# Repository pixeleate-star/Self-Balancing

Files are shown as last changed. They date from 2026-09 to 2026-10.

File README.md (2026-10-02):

# Self-Balancing Robot

This is the whole codebase for my **self-balancing robot**. It has the code, circuit connections and setup information needed to make your own two-wheel self-balancing robot using an **ESP32, MPU9250, TB6612FNG motor driver and two BO motors**.

The main idea behind this project is to build a small two-wheel robot that can balance itself upright using an **MPU9250 IMU**. The MPU9250 measures the robot's tilt and angular velocity, while a **PID controller** continuously adjusts the motors to keep the robot balanced.

The ESP32 handles the sensor readings and PID calculations, while the TB6612FNG controls the two BO motors.

## Features

- Self-balancing two-wheel robot
- ESP32 as the main controller
- MPU9250 accelerometer and gyroscope
- PID-based balance control
- Complementary filter for tilt estimation
- Gyroscope calibration on startup
- Adjustable PID parameters
- Adjustable target balance angle
- Motor dead-zone compensation
- Left and right motor trim
- Automatic fall detection
- Automatic motor shutdown when the robot falls
- High-frequency PWM motor control
- TB6612FNG dual motor driver
- Battery powered
- Compact and easy-to-build design

## BOM – Bill of Materials

| Component | Quantity | Price (USD) | Purpose | Purchase Link |
|---|:---:|---:|---|:---:|
| ESP32 Development Board | 1 | $4.18 | Main controller and PID processing | [Buy Here](https://robocraze.com/products/esp32-development-board-with-cp2102-wifi-bluetooth-dual-core-30-pin) |
| MPU9250 Module | 1 | $3.87 | Accelerometer and gyroscope for tilt sensing | [Buy Here](https://robocraze.com/products/mpu-9250-module) |
| 200 RPM BO Motor | 2 | $0.63 each | Left and right drive motors | [Buy Here](https://robocraze.com/products/200-rpm-single-shaft-bo-motor-straight) |
| BO Motor Wheels | 1 pack (4 pcs) | $0.94 | Robot wheels | [Buy Here](https://robocraze.com/products/bo-motor-wheels-4-pcs) |
| TB6612FNG Dual DC Motor Driver | 1 | $1.41 | Drives both BO motors | [Buy Here](https://robocraze.com/products/tb6612fng-dual-dc-motor-driver) |
| Battery | 2 | $2 | Power source | [Buy Here](https://robocraze.com/products/3-7v-2500mah-18650-li-ion-battery) |
| Battery Holder | 1 | $0.25 | Battery connection | [Buy Here](https://robocraze.com/products/18650-2-cell-holder) |
| Buck Convertor | 1 | $0.6 | To give stable 5V to ESP | [Buy Here](https://robocraze.com/products/lm2596-dc-dc-buck-module) |
| Jumper Wires | As required | — | Electrical connections | - |
| 3D Printed Parts | As required | — | Robot frame and structural parts | Self Printed |

## Circuit Diagram

I have added the complete circuit diagram below. You can use it as a reference while wiring your own self-balancing robot.


I know it looks a mesh so here's a link to circuit you can check it out https://app.cirkitdesigner.com/project/33cf55be-d292-4ee9-8185-b1da4f74aae1

### Main Connections

**MPU9250 → ESP32**

| MPU9250 | ESP32 |
|---|---|
| VCC | 3.3V |
| GND | GND |
| SDA | GPIO 21 |
| SCL | GPIO 22 |

**TB6612FNG → ESP32**

| TB6612FNG | ESP32 |
|---|---|
| AIN1 | GPIO 25 |
| AIN2 | GPIO 26 |
| PWMA | GPIO 27 |
| BIN1 | GPIO 32 |
| BIN2 | GPIO 33 |
| PWMB | GPIO 14 |
| STBY | GPIO 13 |
| VCC | 3.3V |
| GND | GND |

**Motors**

| TB6612FNG | Motor |
|---|---|
| AO1 / AO2 | Left BO Motor |
| BO1 / BO2 | Right BO Motor |

The motor power supply should be connected to the **VM** input of the TB6612FNG according to the voltage requirements of your motors.

The ESP32 and MPU9250 should use a suitable regulated supply, and **all grounds must be connected together**.

## How to Build this...

**step 1:** First get all the components mentioned in the BOM. The main parts required are the ESP32, MPU9250, TB6612FNG, two BO motors, wheels and a suitable battery.

**step 2:** Connect the MPU9250 to the ESP32. Connect SDA to GPIO 21 and SCL to GPIO 22. Connect VCC to 3.3V and GND to GND.

**step 3:** Connect the TB6612FNG to the ESP32 according to the connection table above. Connect the two BO motors to the A and B motor outputs.

**step 4:** Connect the motor battery to the VM and GND terminals of the TB6612FNG. Make sure the battery voltage is suitable for the motors and motor driver.

**step 5:** Connect the ESP32 power supply separately through a suitable regulated supply if required. Do not connect an unregulated motor battery directly to a 3.3V ESP32 pin.

**step 6:** Upload the self-balancing code to the ESP32. In Arduino IDE select the appropriate ESP32 board for your hardware.

**step 7:** Once the ESP32 starts, keep the robot completely still and upright during startup. The code takes multiple readings from the MPU9250 gyroscope and calculates the gyro bias automatically.

**step 8:** After calibration, hold the robot and slowly tilt it forward and backward. Check the motor direction before allowing the robot to stand freely.

When the robot tilts forward:

**Forward tilt → Motors should drive forward → Robot returns upright**

When the robot tilts backward:

**Backward tilt → Motors should drive backward → Robot returns upright**

If the motor direction is reversed, invert the PID output in the code.

**step 9:** Place the robot on a flat surface and carefully allow it to balance. Start with conservative PID values and tune the controller gradually.

**step 10:** Finally, assemble everything inside the robot frame. The exact placement of the MPU9250 matters because its orientation determines how the robot measures its tilt.

## PID Tuning

The main PID parameters can be adjusted directly in the code:

float Kp = 28.0;
float Ki = 0.6;
float Kd = 1.2;

float targetAngle = 0.0;

The parameters control the balancing behavior:

| Parameter | Purpose |
|---|---|
| `Kp` | Controls how strongly the robot reacts to tilt |
| `Ki` | Corrects long-term balance error |
| `Kd` | Controls damping and reduces oscillation |
| `targetAngle` | Sets the desired upright angle |

For tuning, start with:

Ki = 0;

Increase `Kp` until the robot starts reacting strongly to falling.

Then increase `Kd` until the robot becomes less oscillatory.

Finally, add a small amount of `Ki` if the robot consistently leans in one direction.

## Motor Calibration

The motors may not rotate at exactly the same speed even when they receive the same PWM value.

The code includes adjustable motor trim:

float leftTrim = 1.00;
float rightTrim = 1.00;

If the robot constantly moves toward one side while balancing, these values can be adjusted.

For example:

float leftTrim = 1.00;
float rightTrim = 0.96;

The exact values depend on the motors, gearbox, wheels and physical construction of the robot.

## Motor Dead Zone

BO motors usually do not start moving at very low PWM values.

The code therefore includes:

int motorDeadZone = 55;

If the motors don't respond to small corrections, increase this value.

If the robot makes unnecessarily large movements around the balance point, reduce it.

## Fall Detection

The robot automatically stops the motors when the measured angle exceeds the configured safety limit:

float fallAngle = 35.0;

This prevents the motors from continuously running when the robot has already fallen over.

After the robot is placed upright again, the controller can resume balancing.

## Code

The main code uses:

- `Wire.h` for I²C communication with the MPU9250
- MPU9250 accelerometer for tilt estimation
- MPU9250 gyroscope for angular velocity
- Complementary filter for stable angle estimation
- PID control for balancing
- ESP32 PWM for motor control
- TB6612FNG for driving the two BO motors

The main parameters can be adjusted directly in the code:

float Kp = 28.0;
float Ki = 0.6;
float Kd = 1.2;

float targetAngle = 0.0;

float complementaryAlpha = 0.98;

int motorDeadZone = 55;

float leftTrim = 1.00;
float rightTrim = 1.00;

## Known Issues

1. The robot requires accurate PID tuning for stable balancing.
2. The motor direction depends on the physical wiring of the BO motors.
3. The MPU9250 needs to remain still during startup gyro calibration.
4. Different MPU9250 modules can have slightly different gyro offsets.
5. Motor speed can vary between individual BO motors.
6. The physical position and orientation of the MPU9250 affects the balance angle.
7. Battery voltage affects motor response and balancing performance.
8. Wheel size and robot center of gravity significantly affect stability.
9. Very low PWM values may not be enough to start the BO motors.
10. A poorly centered or mechanically flexible frame can make balancing significantly harder.
11. The robot can become unstable if the battery voltage drops too low.
12. The PID parameters may need to be changed when the robot's weight, wheels or motor gearing are changed.

## CAD Models





## Working Principle

The MPU9250 continuously measures the robot's orientation.

The accelerometer provides information about the direction of gravity, while the gyroscope measures how quickly the robot is rotating.

These measurements are combined using a **complementary filter** to estimate the robot's current tilt angle.

The PID controller then calculates how much the motors need to move:

MPU9250
   ↓
Accelerometer + Gyroscope
   ↓
Complementary Filter
   ↓
Tilt Angle
   ↓
PID Controller
   ↓
Motor Output
   ↓
TB6612FNG
   ↓
BO Motors
   ↓
Robot moves back toward upright position

The controller continuously repeats this process at a high frequency, allowing the robot to make rapid corrections and remain balanced.

## Final Result

The whole idea is pretty simple but the control system makes it interesting — instead of manually controlling the robot, the robot continuously measures its own tilt and moves the wheels automatically to keep itself upright.

full video---- https://drive.google.com/file/d/15Oyu7o3CPmcscNef3DqKq84Rv_wBlsnM/view?usp=sharing

It is a compact introduction to **IMU sensing, sensor fusion, PID control, motor control and embedded robotics**, all combined into one project.

working video: https://youtube.com/shorts/BoeQEbhFIXY

mine bot------


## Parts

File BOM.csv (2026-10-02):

Component | Quantity | Price (USD) | Purpose | Purchase Link
ESP32 Development Board | 1 | $4.18 | Main controller and PID processing | https://robocraze.com/products/esp32-development-board-with-cp2102-wifi-bluetooth-dual-core-30-pin
MPU9250 Module | 1 | $3.87 | Accelerometer and gyroscope for tilt sensing | https://robocraze.com/products/mpu-9250-module
200 RPM BO Motor | 2 | $0.63 each | Left and right drive motors | https://robocraze.com/products/200-rpm-single-shaft-bo-motor-straight
BO Motor Wheels | 1 pack (4 pcs) | $0.94 | Robot wheels | https://robocraze.com/products/bo-motor-wheels-4-pcs
TB6612FNG Dual DC Motor Driver | 1 | $1.41 | Drives both BO motors | https://robocraze.com/products/tb6612fng-dual-dc-motor-driver
Battery | 2 | $2 | Power source | https://robocraze.com/products/3-7v-2500mah-18650-li-ion-battery
Battery Holder | 1 | $0.25 | Battery connection | https://robocraze.com/products/18650-2-cell-holder
Buck Convertor | 1 | $0.6 | To give stable 5V to ESP | https://robocraze.com/products/lm2596-dc-dc-buck-module
Jumper Wires | As required | — | Electrical connections | -
3D Printed Parts | As required | — | Robot frame and structural parts | Self Printed

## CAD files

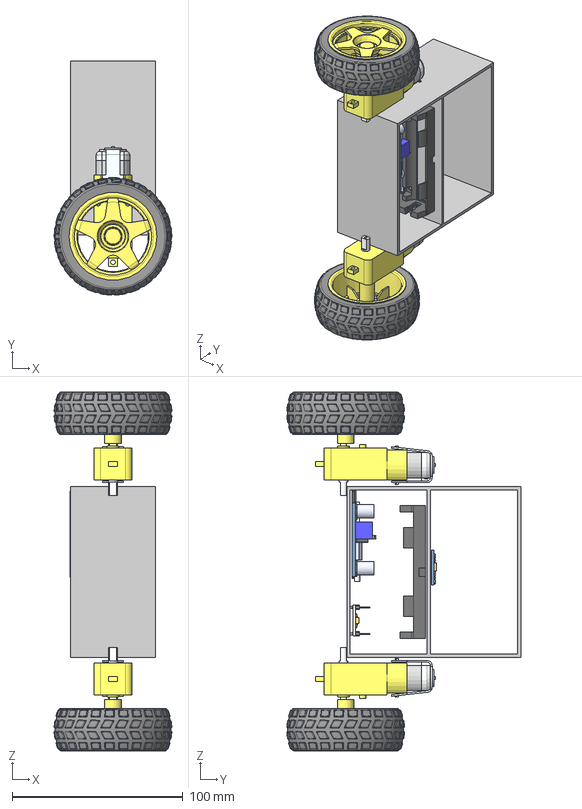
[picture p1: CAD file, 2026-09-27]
CAD/self balancing.step
68.9 x 137.1 x 210.0 mm

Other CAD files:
CAD/self balancing.f3z

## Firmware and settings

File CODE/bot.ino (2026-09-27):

#include <Wire.h>

#define MPU_ADDR 0x68

#define SDA_PIN 21
#define SCL_PIN 22

#define AIN1 25
#define AIN2 26
#define PWMA 27

#define BIN1 32
#define BIN2 33
#define PWMB 14

#define STBY 13

#define PWM_FREQ 20000
#define PWM_RES 8

#define PWM_A 0
#define PWM_B 1

float Kp = 28.0;
float Ki = 0.6;
float Kd = 1.2;

float targetAngle = 0.0;

float complementaryAlpha = 0.98;

float integralLimit = 80.0;

int motorDeadZone = 55;

float leftTrim = 1.00;
float rightTrim = 1.00;

int maxPWM = 255;

float fallAngle = 35.0;

float maxAcceleration = 100.0;

float angle = 0.0;
float gyroBias = 0.0;

float integral = 0.0;

float previousOutput = 0.0;

unsigned long lastMicros = 0;

const uint32_t CONTROL_PERIOD_US = 4000;

void writeRegister(uint8_t reg, uint8_t value) {
  Wire.beginTransmission(MPU_ADDR);
  Wire.write(reg);
  Wire.write(value);
  Wire.endTransmission();
}

void readMPU(
  int16_t &ax,
  int16_t &ay,
  int16_t &az,
  int16_t &gx,
  int16_t &gy,
  int16_t &gz
) {
  Wire.beginTransmission(MPU_ADDR);
  Wire.write(0x3B);
  Wire.endTransmission(false);

  Wire.requestFrom(MPU_ADDR, 14);

  ax = ((int16_t)Wire.read() << 8) | Wire.read();
  ay = ((int16_t)Wire.read() << 8) | Wire.read();
  az = ((int16_t)Wire.read() << 8) | Wire.read();

  Wire.read();
  Wire.read();

  gx = ((int16_t)Wire.read() << 8) | Wire.read();
  gy = ((int16_t)Wire.read() << 8) | Wire.read();
  gz = ((int16_t)Wire.read() << 8) | Wire.read();
}

void setMotorA(int speed) {
  speed = constrain(speed, -255, 255);

  if (speed > 0) {
    digitalWrite(AIN1, HIGH);
    digitalWrite(AIN2, LOW);
    ledcWrite(PWM_A, speed);
  }
  else if (speed < 0) {
    digitalWrite(AIN1, LOW);
    digitalWrite(AIN2, HIGH);
    ledcWrite(PWM_A, -speed);
  }
  else {
    digitalWrite(AIN1, LOW);
    digitalWrite(AIN2, LOW);
    ledcWrite(PWM_A, 0);
  }
}

void setMotorB(int speed) {
  speed = constrain(speed, -255, 255);

  if (speed > 0) {
    digitalWrite(BIN1, HIGH);
    digitalWrite(BIN2, LOW);
    ledcWrite(PWM_B, speed);
  }
  else if (speed < 0) {
    digitalWrite(BIN1, LOW);
    digitalWrite(BIN2, HIGH);
    ledcWrite(PWM_B, -speed);
  }
  else {
    digitalWrite(BIN1, LOW);
    digitalWrite(BIN2, LOW);
    ledcWrite(PWM_B, 0);
  }
}

int applyDeadZone(float value) {
  if (value == 0) {
    return 0;
  }

  float sign = value > 0 ? 1.0 : -1.0;

  float magnitude = abs(value);

  if (magnitude < 1.0) {
    return 0;
  }

  magnitude = motorDeadZone +
              (magnitude / maxPWM) *
              (maxPWM - motorDeadZone);

  magnitude = constrain(magnitude, motorDeadZone, maxPWM);

  return (int)(sign * magnitude);
}

void setMotors(float output) {
  output = constrain(output, -maxPWM, maxPWM);

  float left = output * leftTrim;
  float right = output * rightTrim;

  left = applyDeadZone(left);
  right = applyDeadZone(right);

  setMotorA(left);
  setMotorB(right);
}

void stopMotors() {
  setMotorA(0);
  setMotorB(0);
}

void calibrateGyro() {
  const int samples = 2500;

  long sum = 0;

  stopMotors();

  delay(500);

  for (int i = 0; i < samples; i++) {
    int16_t ax, ay, az, gx, gy, gz;

    readMPU(ax, ay, az, gx, gy, gz);

    sum += gy;

    delayMicroseconds(1000);
  }

  gyroBias = (float)sum / samples;
}

float getAccelAngle(int16_t ax, int16_t az) {
  return atan2((float)ax, (float)az) * 180.0 / PI;
}

void setupMPU() {
  writeRegister(0x6B, 0x00);

  delay(100);

  writeRegister(0x1A, 0x03);

  writeRegister(0x1B, 0x00);

  writeRegister(0x1C, 0x00);

  writeRegister(0x19, 0x04);
}

void setup() {
  Serial.begin(115200);

  Wire.begin(SDA_PIN, SCL_PIN);
  Wire.setClock(400000);

  pinMode(AIN1, OUTPUT);
  pinMode(AIN2, OUTPUT);

  pinMode(BIN1, OUTPUT);
  pinMode(BIN2, OUTPUT);

  pinMode(STBY, OUTPUT);

  digitalWrite(STBY, HIGH);

  ledcSetup(PWM_A, PWM_FREQ, PWM_RES);
  ledcSetup(PWM_B, PWM_FREQ, PWM_RES);

  ledcAttachPin(PWMA, PWM_A);
  ledcAttachPin(PWMB, PWM_B);

  setupMPU();

  delay(500);

  calibrateGyro();

  int16_t ax, ay, az, gx, gy, gz;

  readMPU(ax, ay, az, gx, gy, gz);

  angle = getAccelAngle(ax, az);

  lastMicros = micros();

  stopMotors();

  delay(500);
}

void loop() {
  uint32_t now = micros();

  if ((uint32_t)(now - lastMicros) < CONTROL_PERIOD_US) {
    return;
  }

  float dt = (now - lastMicros) / 1000000.0;

  lastMicros = now;

  int16_t ax, ay, az, gx, gy, gz;

  readMPU(ax, ay, az, gx, gy, gz);

  float accelX = (float)ax / 16384.0;
  float accelY = (float)ay / 16384.0;
  float accelZ = (float)az / 16384.0;

  float accelerationMagnitude =
      sqrt(
        accelX * accelX +
        accelY * accelY +
        accelZ * accelZ
      );

  if (accelerationMagnitude > maxAcceleration / 9.81) {
    return;
  }

  float accelAngle = getAccelAngle(ax, az);

  float gyroRate = ((float)gy - gyroBias) / 131.0;

  angle =
      complementaryAlpha *
      (angle + gyroRate * dt)
      +
      (1.0 - complementaryAlpha) *
      accelAngle;

  if (abs(angle) > fallAngle) {
    stopMotors();

    integral = 0;
    previousOutput = 0;

    return;
  }

  float error = targetAngle - angle;

  integral += error * dt;

  integral = constrain(
      integral,
      -integralLimit,
      integralLimit
  );

  float P = Kp * error;

  float I = Ki * integral;

  float D = -Kd * gyroRate;

  float output = P + I + D;

  output = constrain(
      output,
      -maxPWM,
      maxPWM
  );

  float maxChange = 30.0;

  if (output > previousOutput + maxChange) {
    output = previousOutput + maxChange;
  }

  if (output < previousOutput - maxChange) {
    output = previousOutput - maxChange;
  }

  previousOutput = output;

  setMotors(output);

  static uint32_t lastPrint = 0;

  if (millis() - lastPrint > 100) {
    lastPrint = millis();

    Serial.print("Angle: ");
    Serial.print(angle, 2);

    Serial.print(" | Gyro: ");
    Serial.print(gyroRate, 2);

    Serial.print(" | P: ");
    Serial.print(P, 2);

    Serial.print(" | I: ");
    Serial.print(I, 2);

    Serial.print(" | D: ");
    Serial.print(D, 2);

    Serial.print(" | OUT: ");
    Serial.println(output, 2);
  }
}
